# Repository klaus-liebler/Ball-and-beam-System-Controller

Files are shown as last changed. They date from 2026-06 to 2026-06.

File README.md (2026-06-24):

# Ball-and-beam-System-Controller

Das Projekt umfasst:
- Leiterplattenentwicklung (KiCad)
- Simulationsmodelle (MATLAB / Simulink)

Inhalte:
- KiCad: Schaltplan und PCB-Layout
- Simulink: Systemsimulation

Hardwarekomponenten:
- ESP32-S3-ETH:
  - Datenblatt -> [ESP32-S3 Datasheet (EN)](./datenblätter/Esp32-s3_datasheet_en.pdf)
  - Schematic -> [ESP32-S3 ETH Schematic](./datenblätter/ESP32-S3-ETH-Schematic.pdf)
- ESP32-DevKitC:
  - Datenblatt -> [ESP32 DevKitC Datenblatt](./Datenblätter/ESP32DevkitC.pdf)
  - Schematic -> [ESP32 DevKitC Schematic](./datenblätter/esp32_devkitc_Schematics.pdf)
- 2 Time of Flight Sensoren:
  - Shop ->
  - Datenblatt -> 
- Hall Sensor, AS5600
  - Datenblatt -> [AS5600 Sensor Datenblatt](./datenblätter/AS5600-ASOM.pdf)
- Servormotor, Feetech STS3215:
  - Shop: https://eckstein-shop.de/feetech-st-3215-c018-servo
  - Datenblatt: 
  Datenblatt -> 
- TFT Display:
  Shop -> https://shorturl.at/0loGT
  Datenblatt -> 
- M12 Stecker:
  Shop -> https://shorturl.at/a9XPe
  Datenblatt -> 

Autor: Marvin Schultz

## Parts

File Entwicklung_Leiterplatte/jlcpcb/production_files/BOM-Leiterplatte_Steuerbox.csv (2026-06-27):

Comment | Designator | Footprint | LCSC | Quantity
Spannungsversorgung | Spannungsversorgung1 | PhoenixContact_MCV_1,5_2-G-3.5_1x02_P3.50mm_Vertical |  | 1
6k8 | R2 | R_0805_2012Metric_Pad1.20x1.40mm_HandSolder |  | 1
62R | R8 | R_0805_2012Metric_Pad1.20x1.40mm_HandSolder |  | 1
Status_ESP32-DevkitC | LED2 | LSY876P2S11 |  | 1
22k | R5 | R_0805_2012Metric_Pad1.20x1.40mm_HandSolder |  | 1
62R | R7 | R_0805_2012Metric_Pad1.20x1.40mm_HandSolder |  | 1
100k | R1 | R_0805_2012Metric_Pad1.20x1.40mm_HandSolder |  | 1
ESP32-S3-ETH | U1 | ESP32-S3-ETH |  | 1
DCDC-24V5V | DCDC-24V5V1 | DCDC |  | 1
Schrittmotor | Schrittmotor1 | PhoenixContact_MCV_1,5_4-G-3.5_1x04_P3.50mm_Vertical |  | 1
10k | R4 | R_0805_2012Metric_Pad1.20x1.40mm_HandSolder |  | 1
Conn_01x07_Pin | LCDModuleST7735 | TFT-Display |  | 1
ESP32-DevKitC | U2 | ESP32-DevKitC |  | 1
Status-ESP32-ETH | LED1 | LSY876P2S11 |  | 1
DCDC-24V9V | DCDC-24V9V1 | DCDC |  | 1
10k | R6 | R_0805_2012Metric_Pad1.20x1.40mm_HandSolder |  | 1
51k | R3 | R_0805_2012Metric_Pad1.20x1.40mm_HandSolder |  | 1
MotorDriver | MotorDriver1 | PhoenixContact_MCV_1,5_8-G-3.5_1x08_P3.50mm_Vertical |  | 1
Endlage | Endlage1 | Liebler_Connector |  | 1
Hall-Sensor | Hall-Sensor1 | Liebler_Connector |  | 1
ToF-Vereinzler | ToF-Vereinzler1 | Liebler_Connector |  | 1
Schrittmotor | Schrittmotor2 | Liebler_Connector |  | 1
Boot-ESP-ETH | Boot_ESP_ETH1 | SW_PUSH_6mm_H13mm |  | 1
Servo-Balancer | ServoBalancer1 | Liebler_Connector |  | 1
Boot-ESP-DevkitC | Boot_ESP_DevkitC1 | SW_PUSH_6mm_H13mm |  | 1
Servo-Vereinzler | ServoVereinzler1 | Liebler_Connector |  | 1
ToF-Balancer | ToFBalancer1 | Liebler_Connector |  | 1

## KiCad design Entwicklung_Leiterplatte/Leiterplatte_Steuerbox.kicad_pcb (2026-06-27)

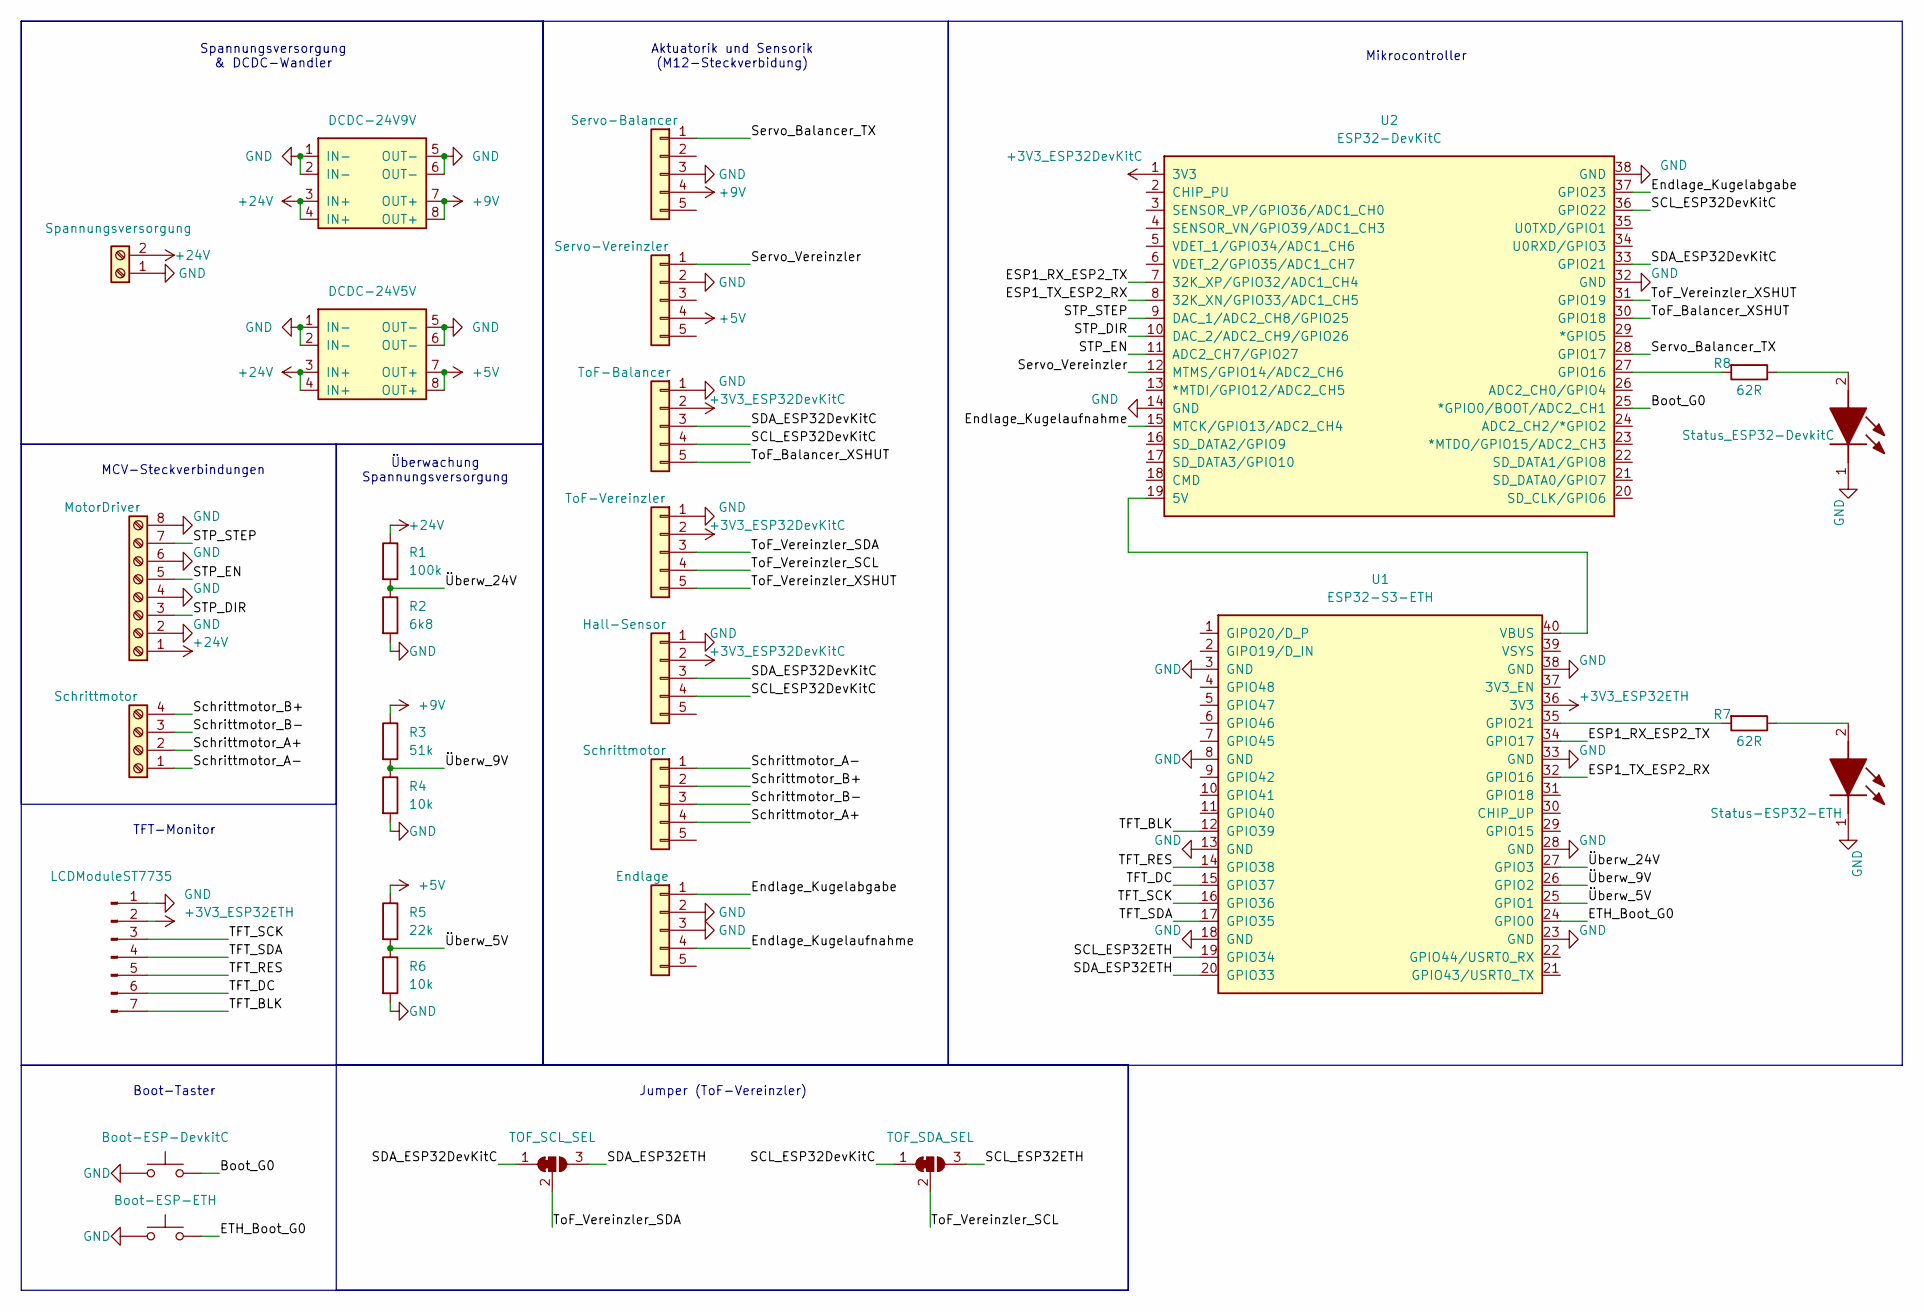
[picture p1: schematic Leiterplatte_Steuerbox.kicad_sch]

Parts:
Boot_ESP_DevkitC1: Boot-ESP-DevkitC; SW_PUSH_6mm_H13mm
Boot_ESP_ETH1: Boot-ESP-ETH; SW_PUSH_6mm_H13mm
DCDC-24V5V1: DCDC-24V5V; DCDC
DCDC-24V9V1: DCDC-24V9V; DCDC
Endlage1: Endlage; Liebler_Connector
Hall-Sensor1: Hall-Sensor; Liebler_Connector
JP1: TOF_SDA_SEL; SolderJumper-3_P1.3mm_Bridged2Bar12_RoundedPad1.0x1.5mm_Num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
JP2: TOF_SCL_SEL; SolderJumper-3_P1.3mm_Bridged2Bar12_RoundedPad1.0x1.5mm_Num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
LCDModuleST7735: Conn_01x07_Pin; TFT-Display
LED1: Status-ESP32-ETH; LSY876P2S11; Mouser Part Number 720-LSY876-P2S1-1-Z
LED2: Status_ESP32-DevkitC; LSY876P2S11; Mouser Part Number 720-LSY876-P2S1-1-Z
MotorDriver1: MotorDriver; PhoenixContact_MCV_1,5_8-G-3.5_1x08_P3.50mm_Vertical
R1: 100k; R_0805_2012Metric_Pad1.20x1.40mm_HandSolder
R2: 6k8; R_0805_2012Metric_Pad1.20x1.40mm_HandSolder
R3: 51k; R_0805_2012Metric_Pad1.20x1.40mm_HandSolder
R4, R6: 10k; R_0805_2012Metric_Pad1.20x1.40mm_HandSolder
R5: 22k; R_0805_2012Metric_Pad1.20x1.40mm_HandSolder
R7, R8: 62R; R_0805_2012Metric_Pad1.20x1.40mm_HandSolder
Schrittmotor1: Schrittmotor; PhoenixContact_MCV_1,5_4-G-3.5_1x04_P3.50mm_Vertical
Schrittmotor2: Schrittmotor; Liebler_Connector
ServoBalancer1: Servo-Balancer; Liebler_Connector
ServoVereinzler1: Servo-Vereinzler; Liebler_Connector
Spannungsversorgung1: Spannungsversorgung; PhoenixContact_MCV_1,5_2-G-3.5_1x02_P3.50mm_Vertical
ToF-Vereinzler1: ToF-Vereinzler; Liebler_Connector
ToFBalancer1: ToF-Balancer; Liebler_Connector
U1: ESP32-S3-ETH
U2: ESP32-DevKitC

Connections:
+3V3_ESP32DevKitC: Hall-Sensor1.2, ToF-Vereinzler1.2, ToFBalancer1.2, U2.1 (3V3)
+3V3_ESP32ETH: LCDModuleST7735.2, U1.36 (3V3)
+5V: DCDC-24V5V1.7 (OUT+), DCDC-24V5V1.8 (OUT+), R5.1, ServoVereinzler1.4
+9V: DCDC-24V9V1.7 (OUT+), DCDC-24V9V1.8 (OUT+), R3.1, ServoBalancer1.4
+24V: DCDC-24V5V1.3 (IN+), DCDC-24V5V1.4 (IN+), DCDC-24V9V1.3 (IN+), DCDC-24V9V1.4 (IN+), MotorDriver1.1, R1.1, Spannungsversorgung1.2
/Boot_G0: Boot_ESP_DevkitC1.2, U2.25 (*GPIO0/BOOT/ADC2_CH1)
/ESP1_RX_ESP2_TX: U1.34 (GPIO17), U2.7 (32K_XP/GPIO32/ADC1_CH4)
/ESP1_TX_ESP2_RX: U1.32 (GPIO16), U2.8 (32K_XN/GPIO33/ADC1_CH5)
/ETH_Boot_G0: Boot_ESP_ETH1.2, U1.24 (GPIO0)
/Endlage_Kugelabgabe: Endlage1.1, U2.37 (GPIO23)
/Endlage_Kugelaufnahme: Endlage1.4, U2.15 (MTCK/GPIO13/ADC2_CH4)
/SCL_ESP32DevKitC: Hall-Sensor1.4, JP1.1 (A), ToFBalancer1.4, U2.36 (GPIO22)
/SCL_ESP32ETH: JP1.3 (B), U1.19 (GPIO34)
/SDA_ESP32DevKitC: Hall-Sensor1.3, JP2.1 (A), ToFBalancer1.3, U2.33 (GPIO21)
/SDA_ESP32ETH: JP2.3 (B), U1.20 (GPIO33)
/STP_DIR: MotorDriver1.3, U2.10 (DAC_2/ADC2_CH9/GPIO26)
/STP_EN: MotorDriver1.5, U2.11 (ADC2_CH7/GPIO27)
/STP_STEP: MotorDriver1.7, U2.9 (DAC_1/ADC2_CH8/GPIO25)
/Schrittmotor_A+: Schrittmotor1.2, Schrittmotor2.4
/Schrittmotor_A-: Schrittmotor1.1, Schrittmotor2.1
/Schrittmotor_B+: Schrittmotor1.4, Schrittmotor2.2
/Schrittmotor_B-: Schrittmotor1.3, Schrittmotor2.3
/Servo_Balancer_TX: ServoBalancer1.1, U2.28 (GPIO17)
/Servo_Vereinzler: ServoVereinzler1.1, U2.12 (MTMS/GPIO14/ADC2_CH6)
/TFT_BLK: LCDModuleST7735.7, U1.12 (GPIO39)
/TFT_DC: LCDModuleST7735.6, U1.15 (GPIO37)
/TFT_RES: LCDModuleST7735.5, U1.14 (GPIO38)
/TFT_SCK: LCDModuleST7735.3, U1.16 (GPIO36)
/TFT_SDA: LCDModuleST7735.4, U1.17 (GPIO35)
/ToF_Balancer_XSHUT: ToFBalancer1.5, U2.30 (GPIO18)
/ToF_Vereinzler_SCL: JP1.2 (C), ToF-Vereinzler1.4
/ToF_Vereinzler_SDA: JP2.2 (C), ToF-Vereinzler1.3
/ToF_Vereinzler_XSHUT: ToF-Vereinzler1.5, U2.31 (GPIO19)
/Überw_5V: R5.2, R6.1, U1.25 (GPIO1)
/Überw_9V: R3.2, R4.1, U1.26 (GPIO2)
/Überw_24V: R1.2, R2.1, U1.27 (GPIO3)
GND: Boot_ESP_DevkitC1.1, Boot_ESP_ETH1.1, DCDC-24V5V1.1 (IN-), DCDC-24V5V1.2 (IN-), DCDC-24V5V1.5 (OUT-), DCDC-24V5V1.6 (OUT-), DCDC-24V9V1.1 (IN-), DCDC-24V9V1.2 (IN-), DCDC-24V9V1.5 (OUT-), DCDC-24V9V1.6 (OUT-), Endlage1.2, Endlage1.3, Hall-Sensor1.1, LCDModuleST7735.1, LED1.1 (K), LED2.1 (K), MotorDriver1.2, MotorDriver1.4, MotorDriver1.6, MotorDriver1.8, R2.2, R4.2, R6.2, ServoBalancer1.3, ServoVereinzler1.2, Spannungsversorgung1.1, ToF-Vereinzler1.1, ToFBalancer1.1, U1.3 (GND), U1.8 (GND), U1.13 (GND), U1.18 (GND), U1.23 (GND), U1.28 (GND), U1.33 (GND), U1.38 (GND), U2.14 (GND), U2.32 (GND), U2.38 (GND)
unnamed: LED1.2 (A), R7.1
unnamed: LED2.2 (A), R8.1
unnamed: R7.2, U1.35 (GPIO21)
unnamed: U1.40 (VBUS), U2.19 (5V)
unnamed: R8.2, U2.27 (GPIO16)

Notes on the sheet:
Boot-Taster
Überwachung Spannungsversorgung
Mikrocontroller
Spannungsversorgung & DCDC-Wandler
Aktuatorik und Sensorik (M12-Steckverbidung)
Jumper (ToF-Vereinzler)
MCV-Steckverbindungen
TFT-Monitor

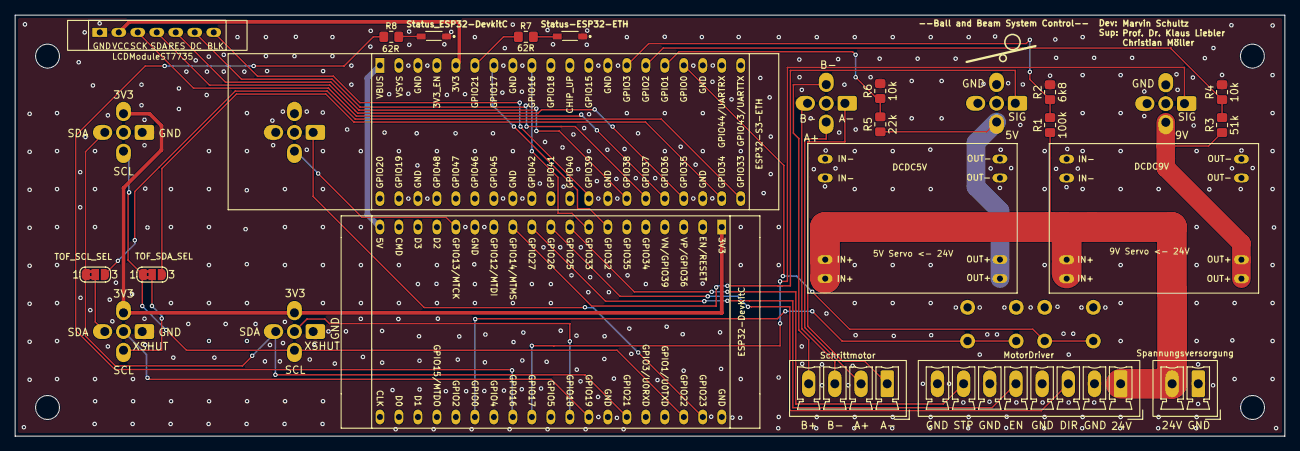
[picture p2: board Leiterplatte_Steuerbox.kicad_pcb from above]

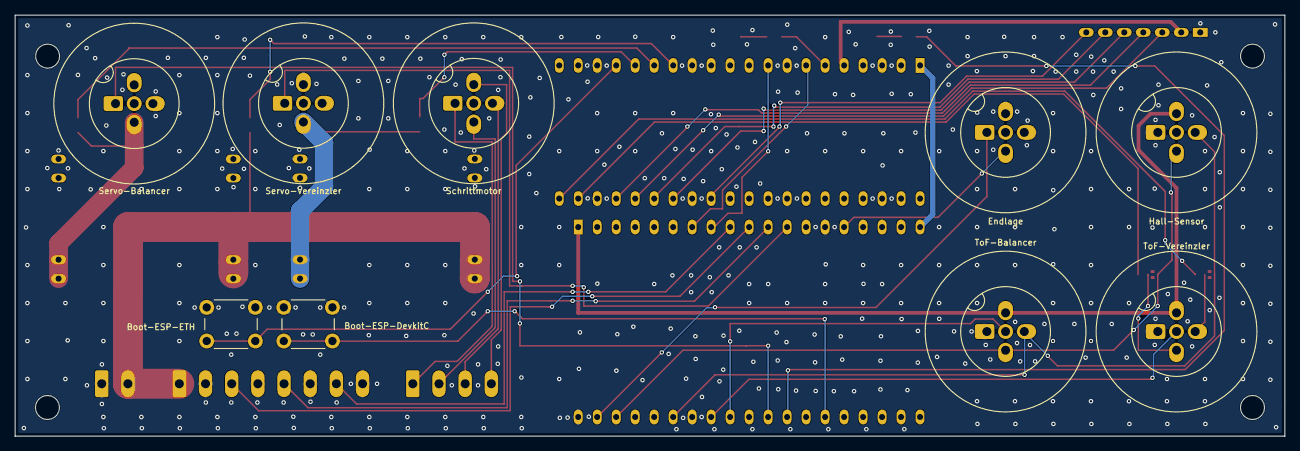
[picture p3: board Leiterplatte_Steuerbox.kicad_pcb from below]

Board: 2 copper layers, 169.8 x 56.3 mm, 33 parts (9 on the bottom side), 42 nets.

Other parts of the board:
H1, H2, H3, H4: MountingHole; MountingHole_3.2mm_M3
